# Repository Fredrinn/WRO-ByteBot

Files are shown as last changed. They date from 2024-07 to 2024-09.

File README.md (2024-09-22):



# WRO-Future Engineers

## ByteBots
### Robotic Solution - ByteBot  

We are Team ByteBots, consisting of Anthony Vargas, Miguelangel Moreno, and Yonathan González. We have developed an autonomous vehicle model to compete in the 2024 season of WRO Future Engineers. This repository houses a wide range of engineering resources related to our autonomous vehicle, designed to tackle challenging speed and skill tests.

## 📝 Contents

* **📸👥 Team Photo**  
  In this section, we present an official photo of our talented ByteBot team. This image captures the spirit of collaboration and dedication that has led us to develop a high-performance autonomous vehicle for the WRO Future Engineers competition. Meet the faces behind the project and discover the collective effort we've invested to achieve our goals.

* **📊📈 Diagram**  
  Here, we present a comprehensive diagram showing the internal workings and structure of our autonomous robot. This diagram provides a clear understanding of how we designed and assembled each essential part of our vehicle, including the sensor system, control unit, actuators, and the overall layout of the components.

* **🛠️🔧 Prototype Images**  
  In this section, you'll find various .pdf files with detailed photos of our robot. You can explore its innovative design, components, and key features up close. These images will allow you to appreciate the quality and precision with which we've built our autonomous vehicle for the WRO Future Engineers competition.

* **💻👩‍💻 Programming**  
  Here you will find the C++ code we developed for the operation of our autonomous robot. This programming file provides detailed information about the navigation algorithms, obstacle detection, and decision-making capabilities of our vehicle. We will be updating the code versions as we progress in the development and optimization of the robot.

* **🤖🎥 Robot Video**  
  In this section, we provide a link to a video located in the vehicle photo folder where you can see our robot in action.

## 📚 Introduction

To optimize the design, the solution was modeled in virtual simulations and used a minimal number of components, allowing for space savings. Significant effort was devoted to optimizing the robot's size and reducing material consumption.

The components used in our prototype are as follows:

- **Microcontroller**: Arduino UNO R3
- **Sensor**: HuskyLens
- **Motors**: DC Motor 6V
- **Servomotor**: Servomotor
- **Other components**: 18650 Batteries, LN298 Module, Jumpers, LEDs

### ⚙️💡 Operation

The journey of the robotic prototype begins with the use of HuskyLens, which provides precise data on the distance between the robot and surrounding objects. Once this data is obtained, the robot enters a second phase of conditional processing that allows it to determine its precise location on the game track.

The prototype can take two distinct approaches to act accordingly. On one hand, it can choose to follow a predefined or pre-programmed route, using sensor data to adjust its trajectory and avoid obstacles. This strategy is based on prior planning and precise execution to achieve the desired goal.

On the other hand, the prototype can also employ a more dynamic and adaptive approach. Using sensor information, the robot can continuously evaluate its surroundings and make real-time decisions to avoid obstacles and reach its goal in the most efficient way possible. This involves a greater capacity for reaction and adaptation to changing game conditions.

####  🚀✨ First Option

The robotic prototype extensively validates HuskyLens data to determine its exact position on the game track. It uses this information to follow a predefined and optimized path that ensures a smooth, fast, and precise journey. The robot maintains a constant and safe pace using the distance data recorded by HuskyLens, avoiding unnecessary stops to check for obstacles in its path.

#### 🧭✨ Second Option

When the ByteBot system detects obstacles through HuskyLens, a conditional logic is activated in Program 2. This program encodes variables and actions for the prototype to make dynamic decisions and adjust its trajectory to avoid obstacles. If an obstacle is detected, the prototype efficiently turns left or right.

The prototype uses HuskyLens data to identify the location and nature of obstacles, determining the optimal direction to avoid them and encoding the necessary instructions for the corresponding turn. This real-time response and adaptation capability is crucial for the prototype's success.

###  🤖⚙️ Action-Reaction

Our action-reaction principle is based on the idea that all vehicle components must work in perfect harmony to achieve optimal performance. The components and actions necessary to generate a reaction based on the received data are as follows:

1. **Sensor Activation**: Upon powering on the vehicle, the first action is to activate HuskyLens, which will provide distance data to locate the prototype at a specific point on the track. These sensors are crucial for obstacle detection and correct vehicle positioning.

2. **Obstacle Detection**: Once the prototype's location is known, the next action is to determine if obstacles are present. To achieve this, we have proposed implementing artificial intelligence (AI) capable of detecting these obstacles. Our team has decided to develop this AI using accessible and user-friendly tools like Teachable Machine. This way, we can leverage machine learning capabilities to train the system in obstacle detection.

3. **Reactions**: Once the prototype knows its location and the presence of obstacles on the track, two possible reactions are triggered:

   3.1. **Predefined Route**: The first reaction is to act as if the prototype is in Round 1, i.e., an obstacle-free track. To achieve this, we use known data such as the initial position, robot speed, track size, robot size, and turning angles. By using mathematical and physical principles, we can calculate a predefined route based on this data, thus avoiding the need to constantly read and analyze known data, saving time and improving efficiency.

   3.2. **Obstacle Detection and Response**: If the prototype detects an obstacle, indicating Round 2, a second reaction occurs. Since Round 2 presents obstacles, it is necessary to reduce the motor speed to avoid errors due to excessive speed.

      3.2.1. **Obstacle Monitoring**: The next action is to monitor the color of the obstacles. This way, we can predefine the vehicle's reaction, which consists of reducing the speed of the DC motors and turning the servomotor in the appropriate direction to provide optimal direction to the robot. This approach allows us to navigate safely and efficiently around obstacles.

<div align="center">

### Made with ❤️ by Bytebots Team

</div>

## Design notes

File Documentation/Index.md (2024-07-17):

# Index

## Documentation
- [Introduction](https://github.com/Fredrinn/WRO-ByteBot/blob/main/Documentation/Introduction.md)
- [README](https://github.com/Fredrinn/WRO-ByteBot/blob/main/README.md)

## Code
- [Bytebot - Code v1.0.1.cpp](https://github.com/Fredrinn/WRO-ByteBot/blob/main/Documentation/Code/Bytebot%20-%20Code%20v1.0.1.cpp)
- [Bytebot - Code v2.0.0.cpp](https://github.com/Fredrinn/WRO-ByteBot/blob/main/Documentation/Code/Bytebot%20-%20Code%20v2.0.0.cpp)
- [code.md](https://github.com/Fredrinn/WRO-ByteBot/blob/main/Documentation/Code/code.md)

## Diagrams
### Component Diagrams
- [Arduino electrical diagram + Motor Driver Shield.png](https://github.com/Fredrinn/WRO-ByteBot/blob/main/Documentation/Diagram/Diagrams/Arduino%20electrical%20diagram%20%2B%20Motor%20Driver%20Shield.png)
- [Arduino physical diagram + Motor Driver Shield.png](https://github.com/Fredrinn/WRO-ByteBot/blob/main/Documentation/Diagram/Diagrams/Arduino%20physical%20diagram%20%2B%20Motor%20Driver%20Shield.png)
- [ByteBots physical diagram.png](https://github.com/Fredrinn/WRO-ByteBot/blob/main/Documentation/Diagram/Diagrams/ByteBots%20physical%20diagram.png)
- [Bytebots electrical diagram.png](https://github.com/Fredrinn/WRO-ByteBot/blob/main/Documentation/Diagram/Diagrams/Bytebots%20electrical%20diagram.png)
- [Diagrams PDF.pdf](https://github.com/Fredrinn/WRO-ByteBot/blob/main/Documentation/Diagram/Diagrams/Diagrams%20PDF.pdf)
- [Esquema ByteBots - Motor Driver Shield + Arduino Mega.fzz](https://github.com/Fredrinn/WRO-ByteBot/blob/main/Documentation/Diagram/Diagrams/Esquema%20ByteBots%20-%20Motor%20Driver%20Shield%20%2B%20Arduino%20Mega.fzz)
- [Esquema_Bytebots.fzz](https://github.com/Fredrinn/WRO-ByteBot/blob/main/Documentation/Diagram/Diagrams/Esquema_Bytebots.fzz)

## Photos
### Team Photos
- [Team Photo.ARW](https://github.com/Fredrinn/WRO-ByteBot/blob/main/Documentation/Photos/Team%C2%B4s%20Photos/Team%20Photo.ARW)

### Robot Photos
- [Lado derecho.jpg](https://github.com/Fredrinn/WRO-ByteBot/blob/main/Documentation/Photos/Vehicle's%20photos/Lado%20derecho.jpg)
- [Lado frontal.jpg](https://github.com/Fredrinn/WRO-ByteBot/blob/main/Documentation/Photos/Vehicle's%20photos/Lado%20frontal.jpg)
- [Lado izquierdo.jpg](https://github.com/Fredrinn/WRO-ByteBot/blob/main/Documentation/Photos/Vehicle's%20photos/Lado%20izquierdo.jpg)
- [Lado trasero.jpg](https://github.com/Fredrinn/WRO-ByteBot/blob/main/Documentation/Photos/Vehicle's%20photos/Lado%20trasero.jpg)
- [Parte de abajo.jpg](https://github.com/Fredrinn/WRO-ByteBot/blob/main/Documentation/Photos/Vehicle's%20photos/Parte%20de%20abajo.jpg)
- [Parte de arriba.jpg](https://github.com/Fredrinn/WRO-ByteBot/blob/main/Documentation/Photos/Vehicle's%20photos/Parte%20de%20arriba.jpg)

### Vehicle Video
- [Vehile-video.md](https://github.com/Fredrinn/WRO-ByteBot/blob/main/Documentation/Photos/Vehicle's%20photos/Vehile-video.md)

## Robot Assembly
- [Assemble Model A.pdf](https://github.com/Fredrinn/WRO-ByteBot/blob/main/Documentation/Robot-assembly/Assemble%20Model%20A.pdf)
- [Assemble Model B.pdf](https://github.com/Fredrinn/WRO-ByteBot/blob/main/Documentation/Robot-assembly/Assemble%20Model%20B.pdf)
- [Model A.png](https://github.com/Fredrinn/WRO-ByteBot/blob/main/Documentation/Robot-assembly/Model%20A.png)
- [Model B.jpg](https://github.com/Fredrinn/WRO-ByteBot/blob/main/Documentation/Robot-assembly/Model%20B.jpg)
- [assembly.md](https://github.com/Fredrinn/WRO-ByteBot/blob/main/Documentation/Robot-assembly/assembly.md)

## Additional Resources
- [01. Diagram Description.md](https://github.com/Fredrinn/WRO-ByteBot/blob/main/Documentation/Diagram/01.%20Diagram%20Description.md)
- [02. Energy management.md](https://github.com/Fredrinn/WRO-ByteBot/blob/main/Documentation/Diagram/02.%20Energy%20management.md)
- [03. Sensor management.md](https://github.com/Fredrinn/WRO-ByteBot/blob/main/Documentation/Diagram/03.%20Sensor%20management.md)
- [04. BOM.md](https://github.com/Fredrinn/WRO-ByteBot/blob/main/Documentation/Diagram/04.%20BOM.md)
- [05. Mobility Management - Motors.md](https://github.com/Fredrinn/WRO-ByteBot/blob/main/Documentation/Diagram/05.%20Mobility%20Management%20-%20Motors.md)

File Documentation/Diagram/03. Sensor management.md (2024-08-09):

# Descripción Técnica y Razones de Selección de Sensores en el Proyecto de Robot

Este proyecto utiliza varios sensores que cumplen funciones clave para la operación del robot. A continuación se proporciona una descripción técnica detallada de cada sensor, junto con las razones por las cuales fueron seleccionados.

## Sensor Ultrasónico HC-SR04
**Función:** Detección de distancia de objetos y ubicación del dispositivo.

**Descripción Técnica:**
- **Rango de detección:** 2 cm a 400 cm, con una precisión de ±3 mm.
- **Frecuencia de operación:** 40 kHz.
- **Voltaje de operación:** 5V DC.

**Por qué es bueno:** Este sensor es ideal para detectar objetos a diferentes distancias con alta precisión, lo que lo convierte en una opción confiable para la navegación autónoma. 

**¿Por qué lo elegimos?** Elegimos el HC-SR04 por su probada efectividad en medir distancias con gran precisión y fiabilidad. Su capacidad para funcionar en un amplio rango de distancias lo hace perfecto para nuestro robot, que necesita detectar obstáculos tanto cercanos como lejanos. Además, su compatibilidad con Arduino y su simplicidad de uso lo hacen muy accesible para el equipo, permitiéndonos concentrarnos en otros aspectos del diseño sin preocuparnos por la complejidad de su implementación.

## Módulo Cámara HuskyLens
**Función:** Visión artificial.

**Descripción Técnica:**
- **Resolución de imagen:** 320x240 píxeles.
- **Interfaces de comunicación:** I2C, UART.
- **Funciones integradas:** Reconocimiento de rostros, seguimiento de objetos, detección de líneas y códigos QR.

**Por qué es buena:** La cámara HuskyLens no solo captura imágenes, sino que también tiene capacidades integradas de procesamiento de visión artificial, lo que reduce la carga de trabajo del microcontrolador. Esto permite que el robot interprete su entorno visualmente y tome decisiones basadas en la información capturada, mejorando significativamente su rendimiento en tareas complejas.

**¿Por qué lo elegimos?** Elegimos la HuskyLens por su avanzada tecnología de visión artificial, que permite a nuestro robot realizar tareas de reconocimiento y seguimiento sin necesidad de procesadores adicionales. Su capacidad para manejar múltiples funciones visuales en tiempo real es crucial para el desarrollo de un robot autónomo sofisticado. Además, su facilidad de uso a través de interfaces como I2C y UART nos brinda flexibilidad en la integración con otros componentes del sistema.

## Módulo Sensor IR (Infrarrojo)
**Función:** Detección de obstáculos cercanos y cobertura de puntos muertos.

**Descripción Técnica:**
- **Rango de detección:** 2 cm a 30 cm.
- **Ángulo de detección:** 35 grados.
- **Voltaje de operación:** 3.3V a 5V DC.

**Por qué es bueno:** Este sensor es perfecto para detectar objetos cercanos que podrían pasar desapercibidos por otros sensores de mayor alcance, como el ultrasónico. Es pequeño, eficiente en consumo de energía, y proporciona una rápida respuesta en la detección de obstáculos, lo que es crucial para evitar colisiones en entornos complejos.

**¿Por qué lo elegimos?** El sensor IR fue seleccionado por su capacidad para detectar obstáculos en áreas que otros sensores, como el ultrasónico, podrían no cubrir debido a su mayor rango de operación. Su tamaño compacto y bajo consumo de energía son ideales para integrar en nuestro robot sin afectar su diseño o autonomía. Además, la rápida respuesta que ofrece es esencial para garantizar la seguridad y eficiencia del robot en situaciones donde se requiere una detección inmediata de obstáculos.

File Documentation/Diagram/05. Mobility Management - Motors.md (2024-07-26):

### 📊 Calculation of Robot Torque 🤖

To calculate the robot torque, we follow these steps:

1. **Determining the force exerted by the robot due to its weight.** ⚖️
2. **Calculating the wheel radius.** 🔄
3. **Calculating torque using force and wheel radius.** 🔧

#### 1. Determination of Force

The total weight of the robot, including the batteries, is \( 0.98 \) kg. The force \( F \) exerted by the robot due to its weight is calculated as:

Arduino  $` F = m \times g `$

Where:
- \( m \) is the mass of the robot (\( 0.98 \) kg)
- \( g \) is the acceleration due to gravity (\( 9.81 \) m/s²)

Arduino  $` F = 0.98 \, \text{kg} \times 9.81 \, \text{m/s}^2 = 9.614 \, \text{N} `$

The force exerted by the robot due to its weight is approximately \( 9.614 \) N.

#### 2. Calculation of Wheel Radius

The diameter of the wheels is \( 64 \) mm. The radius \( r \) is half of the diameter:

Arduino  $` r = \frac{d}{2} = \frac{64 \, \text{mm}}{2} = 32 \, \text{mm} = 0.032 \, \text{m} `$

#### 3. Calculation of Torque

The torque \( \tau \) is calculated using the formula:

Arduino  $` \tau = F \times r `$

Substituting the values of force and radius into the formula:

Arduino  $` \tau = 9.614 \, \text{N} \times 0.032 \, \text{m} = 0.3076 \, \text{Nm} `$

Therefore, the torque exerted by the robot is approximately \( 0.3076 \) Nm.

### ⚙️ Conclusion and Motor Recommendation

The motor should provide at least \( 0.3076 \) Nm of torque. It is recommended to use a \( 12 \) V DC motor with the following specifications:

- **Nominal Torque**: \( 4-5 \) kg-cm (approximately \( 0.4-0.5 \) Nm), to provide a safety margin.
- **Current Capacity**: \( 2-3 \) A, to ensure the motor can handle the required current under load.

#### Example of Suggested Motor

- **12V DC Motor 300RPM with High Torque**: These motors typically have a torque of around \( 4-5 \) kg-cm and can handle higher currents, ensuring the motor can efficiently move the robot.

### 🔍 Final Discussion

Selecting this motor is the best option due to its ability to provide torque greater than required, ensuring smooth and efficient operation of the robot. Additionally, its capability to handle higher currents allows robust operation under various load conditions. This provides a safety margin crucial for avoiding overloads and ensuring motor longevity. Therefore, the \( 12 \) V DC motor with the mentioned specifications is ideal for this project. 🚀

---

### 📊 Cálculo del Torque del Robot 🤖

Para calcular el torque del robot, seguimos estos pasos:

1. **Determinación de la fuerza ejercida por el robot debido a su peso.** ⚖️
2. **Cálculo del radio de las ruedas.** 🔄
3. **Cálculo del torque utilizando la fuerza y el radio de las ruedas.** 🔧

#### 1. Determinación de la Fuerza

El peso total del robot, incluyendo las baterías, es de \( 0.98 \) kg. La fuerza \( F \) ejercida por el robot debido a su peso se calcula como:

Arduino  $` F = m \times g `$

Donde:
- \( m \) es la masa del robot (\( 0.98 \) kg)
- \( g \) es la aceleración debido a la gravedad (\( 9.81 \) m/s²)

Arduino  $` F = 0.98 \, \text{kg} \times 9.81 \, \text{m/s}^2 = 9.614 \, \text{N} `$

La fuerza ejercida por el robot debido a su peso es aproximadamente \( 9.614 \) N.

#### 2. Cálculo del Radio de las Ruedas

El diámetro de las ruedas es \( 64 \) mm. El radio \( r \) es la mitad del diámetro:

Arduino  $` r = \frac{d}{2} = \frac{64 \, \text{mm}}{2} = 32 \, \text{mm} = 0.032 \, \text{m} `$

#### 3. Cálculo del Torque

El torque \( \tau \) se calcula utilizando la fórmula:

Arduino  $` \tau = F \times r `$

Sustituyendo los valores de la fuerza y el radio en la fórmula:

Arduino  $` \tau = 9.614 \, \text{N} \times 0.032 \, \text{m} = 0.3076 \, \text{Nm} `$

Por lo tanto, el torque ejercido por el robot es aproximadamente \( 0.3076 \) Nm.

### ⚙️ Conclusión y Recomendación del Motor

El motor debe proporcionar al menos \( 0.3076 \) Nm de torque. Se recomienda utilizar un motor DC de \( 12 \) V con las siguientes especificaciones:

- **Torque Nominal**: \( 4-5 \) kg-cm (aproximadamente \( 0.4-0.5 \) Nm), para proporcionar un margen de seguridad.
- **Capacidad de Corriente**: \( 2-3 \) A, para asegurar que el motor pueda manejar la corriente requerida bajo carga.

#### Ejemplo de Motor Sugerido

- **Motor DC 12V 300RPM con Alto Torque**: Estos motores suelen tener un torque de alrededor de \( 4-5 \) kg-cm y son capaces de manejar corrientes más altas, asegurando que el motor pueda mover el robot de manera eficiente.

### 🔍 Discusión Final

Seleccionar este motor es la mejor opción debido a su capacidad para proporcionar un torque mayor al requerido, asegurando un funcionamiento suave y eficiente del robot. Además, su capacidad para manejar corrientes más altas permite una operación robusta bajo diversas condiciones de carga. Esto proporciona un margen de seguridad crucial para evitar sobrecargas y asegurar la longevidad del motor. Por lo tanto, el motor DC de \( 12 \) V con las especificaciones mencionadas es ideal para este proyecto. 🚀

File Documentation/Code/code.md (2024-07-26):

# Documentación del Proyecto Bytebots

## C++ Tecnologías Utilizadas

Este proyecto está desarrollado utilizando las siguientes tecnologías y plataformas:

<span>
    Arduino
    C++
</span>

Descripción de la imagen

## C++ Descripción

Este proyecto utiliza un motor servo y un sensor de visión AI HuskyLens para detectar colores y mover el servo según los IDs de color detectados. El proyecto involucra los siguientes componentes:

- **Motor Servo**: Controlado mediante la biblioteca `Servo.h` para moverse a posiciones específicas.
- **HuskyLens**: Un sensor de visión AI que utiliza la biblioteca `HUSKYLENS.h` para la detección y reconocimiento de colores.
- **SoftwareSerial**: Utilizado para comunicar con el HuskyLens mediante comunicación serial.

## C++ Funcionalidad

El sistema opera de la siguiente manera:

1. **Inicialización**: 
   - El motor servo se conecta a un pin especificado.
   - Se inicializa la comunicación serial tanto para el serial estándar como para el serial por software (para HuskyLens).
   - Se inicializa el HuskyLens y se configura para usar el algoritmo de reconocimiento de colores.

2. **Detección de Colores y Control del Servo**:
   - En el bucle principal, el sistema solicita datos del HuskyLens.
   - Si el HuskyLens detecta un color aprendido, lee el resultado.
   - Si el ID de color detectado es `1`, el servo se mueve a la posición izquierda.
   - El sistema luego espera a que se detecte el ID de color `2` para mover el servo a la posición centrada.

3. **Movimiento del Servo y Verificación del Centro**:
   - La función `moverServo` se usa para mover el servo a una posición especificada y verificar si está centrado.
   - La función `verificarCentro` verifica si el servo está dentro del rango de posición centrada e imprime el estado en el monitor serial.

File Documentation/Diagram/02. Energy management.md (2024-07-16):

# ByteBot Battery Configuration

## Overview

This document provides detailed technical information on the battery configuration used in ByteBot. The setup involves six 18650 batteries arranged in a 3S2P configuration, optimizing both voltage and capacity.

## Configuration Details

### Battery Configuration: 3S2P

- **3S (Series)**: Three batteries connected in series to add their voltages.
- **2P (Parallel)**: Two of these series connected in parallel to add their capacities.

### Electrical Specifications

- **Total Voltage (Nominal)**: `11.1V`
- **Total Voltage (Fully Charged)**: `12.6V`
- **Total Capacity (Amperage)**: `4000mAh (4Ah)`

### Charging Information

- **Charge Rate**: Typically 0.5C to 1C
- **Charging Time at 0.5C**: `2 to 3 hours`
- **Charging Time at 1C**: `1.5 to 2 hours`

### Maximum Voltage

- **Maximum Voltage**: `12.6V`

## Technical Summary

This six-cell 18650 battery configuration in a 3S2P arrangement provides a robust solution for applications requiring a balance between high voltage and extended capacity. The nominal voltage of 11.1V ensures stable operation, while the fully charged voltage of 12.6V offers a performance boost when needed. With a total capacity of 4000mAh, ByteBot is equipped for extended periods of operation without frequent recharges.

### ⚡ Voltage Details

- **Nominal Voltage**: `11.1V`
- **Fully Charged Voltage**: `12.6V`

### 🔋 Capacity Details

- **Total Capacity**: `4000mAh (4Ah)`

### ⏳ Charging Time

- **At 0.5C**: `2 to 3 hours`
- **At 1C**: `1.5 to 2 hours`

## Optimization and Safety Reasons

This 3S2P configuration with 18650 batteries is optimal due to its ideal balance between high voltage and high capacity, essential for applications requiring prolonged operation and robust performance, such as ByteBot. By combining batteries in series and parallel, a nominal voltage of 11.1V and a total capacity of 4000mAh is achieved, providing sufficient power without frequent recharges. The approximate weight of this configuration is 270 grams, considering that each 18650 battery weighs around 45 grams.

### Safety Recommendations for 18650 Battery Configuration

1. **Handling and Storage**:
   - Avoid short circuits: Never allow the battery terminals to come into contact with metallic objects.
   - Store in a dry place at room temperature, away from flammable materials.

2. **Mounting**:
   - Use an appropriate holder to keep the batteries firmly in place.
   - Ensure that the series and parallel connections are properly insulated to prevent short circuits.

3. **Charging**:
   - Use a balanced charger specifically for lithium-ion batteries, with overcharge protection.
   - Do not leave batteries charging unattended.

4. **Usage**:
   - Avoid complete battery discharge; keep the voltage above 3V per cell to prolong battery life.
   - Monitor battery temperature during use; if they become too hot, stop operation and let them cool down.

5. **Emergency Handling**:
   - Have a Class D fire extinguisher, suitable for metal fires, on hand in case a battery overheats or catches fire.
   - In case of leakage, avoid contact with skin and eyes; wash with plenty of water and seek medical attention.

This configuration not only maximizes ByteBot's operational efficiency but also meets the necessary safety and reliability standards in advanced robotic engineering, ensuring safe and prolonged performance.

## Additional Resources

For more information on battery configuration, you can check the following resources:

- **Video**: [Battery Configuration](https://youtu.be/Cti496Aw1ew?si=FzMWoOU4gcUDVYFR)
  Battery Configuration (https://youtu.be/Cti496Aw1ew?si=FzMWoOU4gcUDVYFR)

- **Website**: [Building a Lithium-Ion Battery Pack](https://www.facilelectro.es/montar-un-pack-de-baterias-de-litio/)

---

## Energy Consumption by Component

**Arduino Mega 2560:**
- Typical consumption: Approximately 50 mA in active mode. 🤖
- Power supply: 7V to 12V, provided by the 18650 batteries through the Motor Driver Shield. 🔋

**L298N Motor Driver Module:**
- Consumption depends on the motor load. 🛠️
- Power supply: Provided by the 18650 batteries. 🔌

**HC-SR04 Ultrasonic Sensor:**
- Low consumption, typically around 15 mA during measurement. 📏
- Power supply: Provided by the 5V pins on the Arduino. 🔌

**IR Sensor Module:**
- Variable consumption, generally in the range of 20-30 mA depending on the active or inactive state. 🕵️‍♂️
- Power supply: Provided by the 5V pins on the Arduino. 🔌

**Huskylens Camera Module:**
- Power supply: Voltage from 3.3V to 5.0V

## Result of the Debate on Energy Optimization

After extensive debate among team members, it was concluded that our first prototype version had a total of 2 18650 batteries and a weight of 800g, which is below the allowed limit of 1.5kg. This means that adding more batteries would not pose a significant problem. Considering each 18650 battery weighs approximately 45g, adding 4 additional batteries would increase the weight by 180g, bringing the total weight to 980g, still within the permitted limit.

The new battery configuration was designed in a 3S2P arrangement (3 in series and 2 in parallel). In this arrangement, three sets of two batteries in parallel are connected in series to provide a total voltage of 11.1V and an increased capacity of 4000mAh.

This decision was made because with the 7.4V resulting from using only 2 batteries, we could barely utilize 61.6% of a 12V DC motor's capacity. By increasing the number of batteries, the voltage is raised to 11.1V, which allows us to utilize 92.5% of the 12V motor's capacity. This significantly improves the balance between the robot's speed and torque, optimizing its performance in competitions.

In the 3S2P arrangement, each pair of batteries connected in parallel maintains the same nominal voltage of 3.7V but doubles the capacity. Then, by connecting three of these pairs in series, the voltage is tripled to 11.1V while maintaining a total capacity of 4000mAh. This configuration provides an optimal balance between capacity and voltage, ensuring adequate and stable power for all robot components.

---

# Configuración de Baterías de ByteBot

## Descripción General

Este documento proporciona información técnica detallada sobre la configuración de baterías utilizada en ByteBot. La configuración involucra seis baterías 18650 dispuestas en una configuración 3S2P, optimizando tanto el voltaje como la capacidad.

## Detalles de la Configuración

### Configuración de Baterías: 3S2P

- **3S (Serie)**: Tres baterías conectadas en serie para sumar sus voltajes.
- **2P (Paralelo)**: Dos de estas series conectadas en paralelo para sumar sus capacidades.

### Especificaciones Eléctricas

- **Voltaje Total (Nominal)**: `11.1V`
- **Voltaje Total (Completamente Cargadas)**: `12.6V`
- **Capacidad Total (Amperaje)**: `4000mAh (4Ah)`

### Información de Carga

- **Tasa de Carga**: Típicamente 0.5C a 1C
- **Tiempo de Carga a 0.5C**: `2 a 3 horas`
- **Tiempo de Carga a 1C**: `1.5 a 2 horas`

### Voltaje Máximo

- **Voltaje Máximo**: `12.6V`

## Resumen Técnico

Esta configuración de batería de seis celdas 18650 en una disposición 3S2P proporciona una solución robusta para aplicaciones que requieren un equilibrio entre alto voltaje y capacidad extendida. El voltaje nominal de 11.1V asegura una operación estable, mientras que el voltaje completamente cargado de 12.6V ofrece un impulso de rendimiento cuando es necesario. Con una capacidad total de 4000mAh, ByteBot está equipado para períodos extendidos de operación sin recargas frecuentes.

### ⚡ Detalles del Voltaje

- **Voltaje Nominal**: `11.1V`
- **Voltaje Completamente Cargado**: `12.6V`

### 🔋 Detalles de Capacidad

- **Capacidad Total**: `4000mAh (4Ah)`

### ⏳ Tiempo de Carga

- **A 0.5C**: `2 a 3 horas`
- **A 1C**: `1.5 a 2 horas`

## Razones de Optimización y Seguridad

Esta configuración de 3S2P con baterías 18650 es óptima debido a su equilibrio ideal entre alto voltaje y alta capacidad, esencial para aplicaciones que requieren una operación prolongada y un rendimiento robusto, como en el caso de ByteBot. Al combinar baterías en serie y paralelo, se logra un voltaje nominal de 11.1V y una capacidad total de 4000mAh, proporcionando suficiente potencia sin necesidad de recargas frecuentes. El peso aproximado de esta configuración es de 270 gramos, considerando que cada batería 18650 pesa alrededor de 45 gramos.

### Recomendaciones de Seguridad para la Configuración de Baterías 18650

1. **Manipulación y Almacenamiento**:
   - Evitar cortocircuitos: Nunca permita que los terminales de las baterías entren en contacto con objetos metálicos.
   - Almacenar en un lugar seco y a temperatura ambiente, lejos de materiales inflamables.

2. **Montaje**:
   - Usar un soporte adecuado para mantener las baterías firmemente en su lugar.
   - Asegurarse de que las conexiones de serie y paralelo estén correctamente aisladas para prevenir cortocircuitos.

3. **Carga**:
   - Utilizar un cargador balanceado específico para baterías de litio-ion, que tenga protección contra sobrecarga.
   - No dejar las baterías cargándose sin supervisión.

4. **Uso**:
   - Evitar la descarga completa de las baterías; mantener el voltaje por encima de 3V por celda para prolongar su vida útil.
   - Monitorear la temperatura de las baterías durante el uso; si se calientan demasiado, detener la operación y dejar que se enfríen.

5. **Manejo de Emergencias**:
   - Tener un extintor de clase D a mano, adecuado para incendios de metales, en caso de que una batería se sobrecaliente o se incendie.
   - En caso de fuga, evitar el contacto con la piel y los ojos; lavar con abundante agua y buscar atención médica.

Esta configuración no solo maximiza la eficiencia operativa de ByteBot, sino que también cumple con los estándares de seguridad y fiabilidad necesarios en la ingeniería robótica avanzada, garantizando un rendimiento seguro y prolongado.

## Recursos Adicionales

Para obtener más información sobre la configuración de baterías, puedes consultar los siguientes recursos:

- **Video**: [Configuración de Baterías](https://youtu.be/Cti496Aw1ew?si=FzMWoOU4gcUDVYFR)
  Configuración de Baterías (https://youtu.be/Cti496Aw1ew?si=FzMWoOU4gcUDVYFR)

- **Sitio Web**: [Montar un Pack de Baterías de Litio](https://www.facilelectro.es/montar-un-pack-de-baterias-de-litio/)
  
---

## Consumo de Energía por Componente

**Arduino Mega 2560:**
- Consumo típico: Aproximadamente 50 mA en modo activo. 🤖
- Alimentación: 7V a 12V, que provendrá de las baterías 18650 a través del Motor Driver Shield. 🔋

**L298N Motor Driver Module:**
- Consumo depende de la carga del motor. 🛠️
- Alimentación: Proveniente de las baterías 18650. 🔌

**HC-SR04 Ultrasonic Sensor:**
- Consumo bajo, típicamente alrededor de 15 mA durante la medición. 📏
- Alimentación: Proveniente de los pines de 5V del Arduino. 🔌

**IR Sensor Module:**
- Consumo variable, generalmente en el rango de 20-30 mA dependiendo del estado activo o inactivo. 🕵️‍♂️
- Alimentación: Proveniente de los pines de 5V del Arduino. 🔌

**Huskylens Camera Module:**
- Alimentación: Tensión de 3.3V a 5.0V
  
## Resultado del Debate sobre la Optimización de Energía

Después de un extenso debate entre los miembros del equipo, se concluyó que nuestra primera versión del prototipo contaba con un total de 2 baterías 18650 y un peso de 800g, algo por debajo del límite permitido de 1.5kg. Esto significa que añadir más baterías no representaría un gran problema. Considerando que cada batería 18650 pesa aproximadamente 45g, añadir 4 baterías adicionales incrementaría el peso en 180g, llevando el peso total a 980g, aún dentro del límite permitido.

La nueva configuración de las baterías se diseñó en un arreglo 3s2p (3 en serie y 2 en paralelo). En este arreglo, tres conjuntos de dos baterías en paralelo se conectan en serie para proporcionar un voltaje total de 11.1V y una capacidad aumentada de 4000mAh.

Esta decisión se tomó debido a que con los 7.4V resultantes de utilizar solo 2 baterías, apenas podríamos aprovechar el 61.6% de la capacidad de un motor DC de 12V. Al aumentar la cantidad de baterías, se incrementa el voltaje a 11.1V, lo que permite aprovechar un 92.5% de la capacidad del motor de 12V. Esto mejora significativamente el equilibrio entre velocidad y torque del robot, optimizando su rendimiento en las competencias.

En el arreglo 3s2p, cada par de baterías conectadas en paralelo mantiene el mismo voltaje nominal de 3.7V, pero duplica la capacidad. Luego, al conectar tres de estos pares en serie, se triplica el voltaje a 11.1V mientras se mantiene la capacidad total de 4000mAh. Esta configuración proporciona un equilibrio óptimo entre la capacidad y el voltaje, asegurando una alimentación adecuada y estable para todos los componentes del robot.

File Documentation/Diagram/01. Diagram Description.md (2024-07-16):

# Technical Description of System Diagram

## Main Components

1. **Arduino Mega 2560 Board**:
   - Located at the center of the diagram.
   - Provides control and logic for the system.
   - Key connections:
     - Powered by batteries.
     - Sensors and actuators connected to various pins.

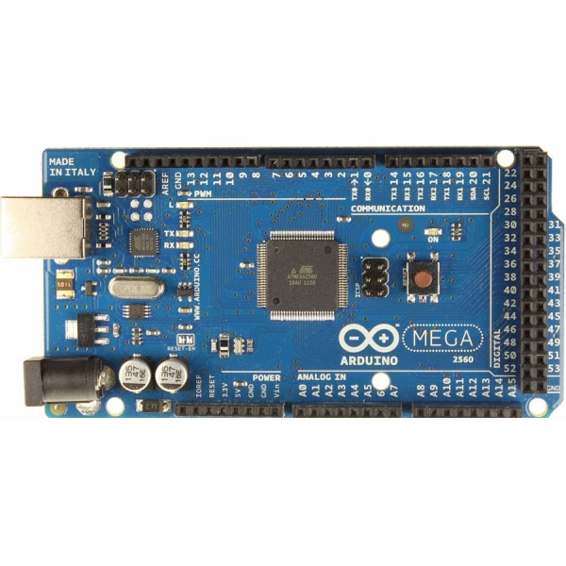
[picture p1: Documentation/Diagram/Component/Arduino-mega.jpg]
Arduino Mega
   <br>

2. **L298N Motor Driver Module**:
   - Positioned to the left of the Arduino board.
   - Controls the DC motor and servo.
   - Key connections:
     - Powered and controlled by Arduino.
     - Outputs to DC motor and servo.

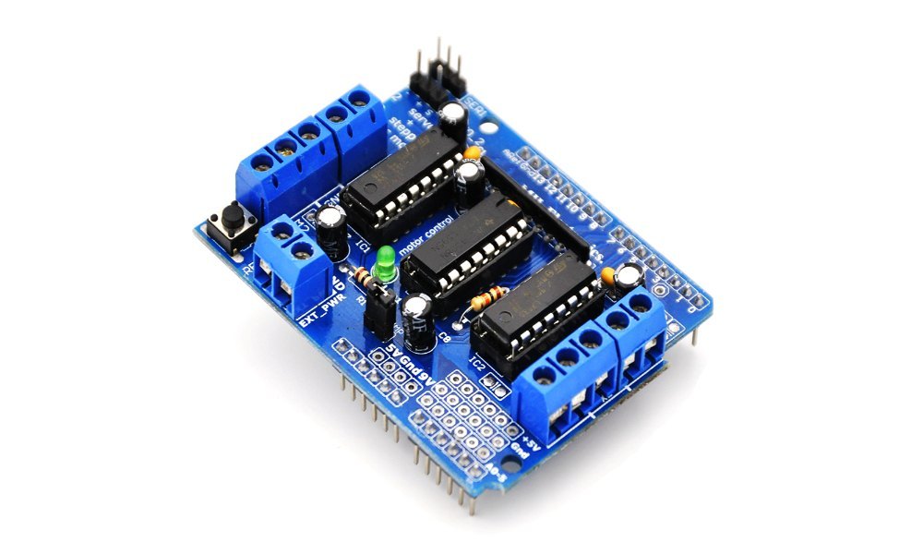
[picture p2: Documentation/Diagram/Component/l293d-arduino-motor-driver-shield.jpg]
L298N Motor Driver
   <br>

3. **18650 Batteries**:
   - Six batteries located on the left, connected in series to provide power.
   - Connection to motor driver and the Arduino board.

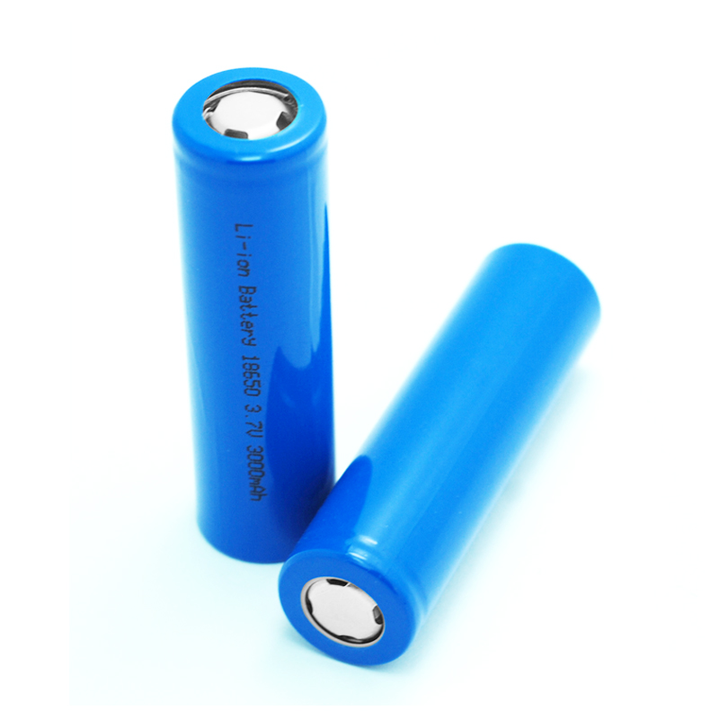
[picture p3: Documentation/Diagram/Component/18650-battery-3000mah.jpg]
18650 Batteries
   <br>

4. **HC-SR04 Ultrasonic Sensor**:
   - Located in the bottom right of the diagram.
   - Used for measuring distances to objects in front of the system.
   - Connections to Arduino digital pins for trigger and echo.

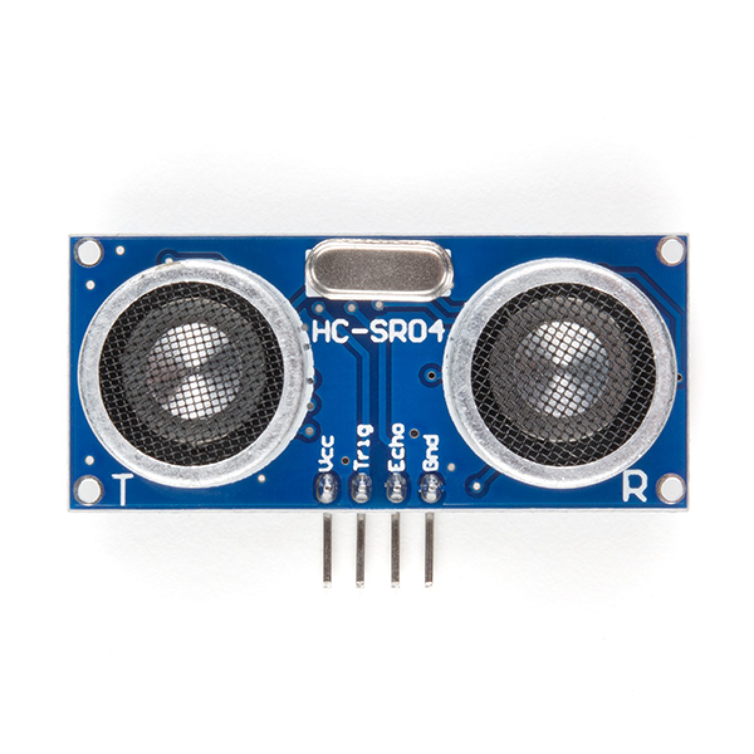
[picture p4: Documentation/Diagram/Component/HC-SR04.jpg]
HC-SR04 Ultrasonic Sensor
   <br>

5. **IR Sensor Module**:
   - Positioned just left of the ultrasonic sensor.
   - Used for detecting nearby obstacles.
   - Connections to Arduino digital pins.

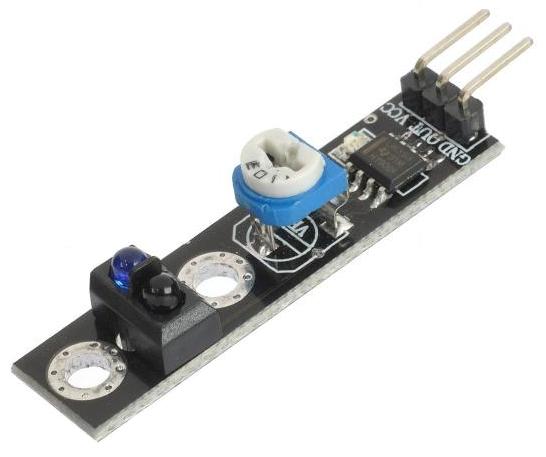
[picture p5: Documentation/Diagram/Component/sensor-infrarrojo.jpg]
IR Sensor
   <br>

6. **Camera Module**:
   - Located in the top right of the diagram.
   - Connected to the Arduino board for image capture.
   - Power and communication connected through specific pins.

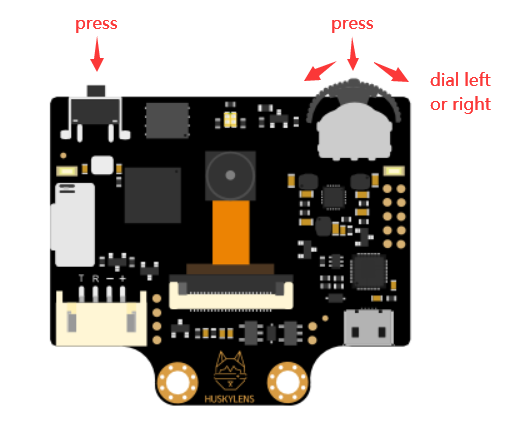
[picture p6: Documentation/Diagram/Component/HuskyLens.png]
Camera Module
   <br>

## Detailed Connections

- **Power**:
  - 18650 batteries are connected in series, providing power to both the L298N motor driver and the Arduino Mega board.
  - Red cables indicate positive voltage connections (+), and black cables indicate ground connections (-).

- **Motor Control**:
  - The L298N module receives control signals from the Arduino board to manage the DC motor and servo.
  - The DC motor is connected to the outputs of the L298N for speed and direction control.
  - The servo motor is also connected to the L298N for position control.

- **Sensors**:
  - The HC-SR04 ultrasonic sensor connects to Arduino digital pins for trigger and echo functionality.
  - The IR sensor module is connected to digital pins for obstacle detection.

- **Communication and Additional Sensors**:
  - The camera module is connected to the Arduino board via specific pins for communication and power.

## Operational Technical Description

The system is designed to function as an autonomous mobile robot. The Arduino Mega board acts as the brain of the system, controlling the movement of the DC motor and servo motor through the L298N module. The 18650 batteries provide the necessary power for the entire system.

The HC-SR04 ultrasonic sensor and IR module are used for obstacle detection, allowing the Arduino to receive data about object proximity and adjust motor direction accordingly to avoid collisions.

The camera module adds vision capabilities to the system, enabling the capture of images or videos that can be processed for navigation or object recognition.

---

# Descripción Técnica del Diagrama del Sistema

## Componentes Principales

1. **Placa Arduino Mega 2560**:
   - Ubicada en el centro del diagrama.
   - Proporciona el control y la lógica para el sistema.
   - Conexiones principales:
     - Alimentación desde baterías.
     - Sensores y actuadores conectados a varios pines.

   Arduino Mega<br>

2. **Módulo Driver de Motores L298N**:
   - Ubicado a la izquierda de la placa Arduino.
   - Controla el motor de corriente continua (DC motor) y el servo.
   - Conexiones principales:
     - Alimentación y control desde Arduino.
     - Salidas a motor DC y servo.

   L298N Motor Driver<br>

3. **Baterías 18650**:
   - Seis baterías ubicadas a la izquierda, conectadas en serie para proporcionar alimentación.
   - Conexión al driver de motores y a la placa Arduino.

   18650 Batteries<br>

4. **Sensor Ultrasónico HC-SR04**:
   - Ubicado en la parte inferior derecha del diagrama.
   - Utilizado para medir la distancia de objetos delante del sistema.
   - Conexiones a pines digitales en Arduino para trigger y echo.

   HC-SR04 Ultrasonic Sensor<br>

5. **Módulo Sensor IR (Infrarrojo)**:
   - Ubicado justo a la izquierda del sensor ultrasónico.
   - Utilizado para la detección de obstáculos cercanos.
   - Conexiones a pines digitales en Arduino.

   Sensor IR<br>

6. **Módulo Cámara**:
   - Ubicado en la parte superior derecha del diagrama.
   - Conectado a la placa Arduino para la captura de imágenes.
   - Alimentación y comunicación conectadas a través de pines específicos.

   Módulo Cámara<br>

## Conexiones Detalladas

- **Alimentación**:
  - Las baterías 18650 están conectadas en serie y alimentan tanto el driver de motores L298N como la placa Arduino Mega.
  - Los cables rojos indican conexiones de voltaje positivo (+) y los cables negros indican conexiones a tierra (-).

- **Control de Motores**:
  - El módulo L298N recibe señales de control desde la placa Arduino para manejar el motor DC y el servo.
  - El motor DC está conectado a las salidas del L298N, permitiendo su control de velocidad y dirección.
  - El servo motor también está conectado al L298N para control de posición.

- **Sensores**:
  - El sensor ultrasónico HC-SR04 tiene conexiones a los pines digitales del Arduino para los pines de trigger y echo.
  - El módulo sensor IR está conectado a pines digitales para detección de obstáculos.

- **Comunicación y Sensores Adicionales**:
  - El módulo cámara está conectado a la placa Arduino mediante pines específicos para comunicación y alimentación.

## Descripción Técnica del Funcionamiento

El sistema está diseñado para funcionar como un robot móvil autónomo. La placa Arduino Mega actúa como el cerebro del sistema, controlando el movimiento del motor DC y el servo motor a través del módulo L298N. Las baterías 18650 proporcionan la energía necesaria para todo el sistema.

El sensor ultrasónico HC-SR04 y el módulo IR se utilizan para la detección de obstáculos, permitiendo que el Arduino reciba datos sobre la proximidad de objetos y ajuste la dirección del motor en consecuencia para evitar colisiones.

La cámara añade capacidades de visión al sistema, permitiendo la captura de imágenes o videos que pueden ser procesados para navegación o reconocimiento de objetos.

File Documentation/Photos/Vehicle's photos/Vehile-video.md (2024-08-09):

### Enlace al Video

<a href="https://www.youtube.com/watch?v=M7r2FSRNm-M?si=92GTvmqhkAq8Kt1_" target="_blank">
    Ver video de funcionamiento del robot
</a>

#### Descripción en Español
Video que muestra el funcionamiento autónomo de nuestro robot utilizando sensores avanzados y algoritmos de inteligencia artificial para una navegación eficiente y segura.

#### Description in English
Video showcasing the autonomous operation of our robot using advanced sensors and AI algorithms for efficient and safe navigation.

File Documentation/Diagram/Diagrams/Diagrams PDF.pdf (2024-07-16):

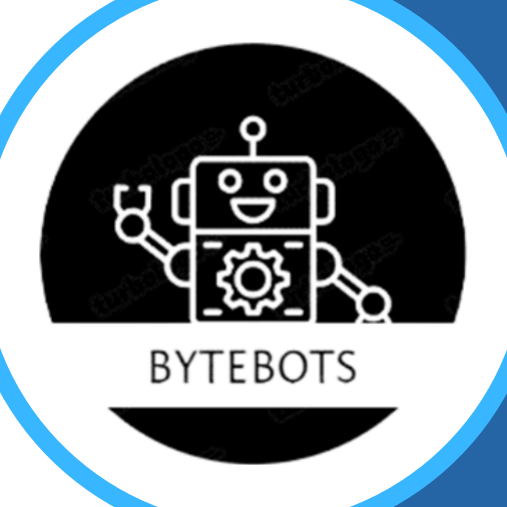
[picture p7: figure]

# DIAGRAMS

# TEAM BYTEBOTS

Let'

s learn together about this wiring diagram and
connection.

# INDEX

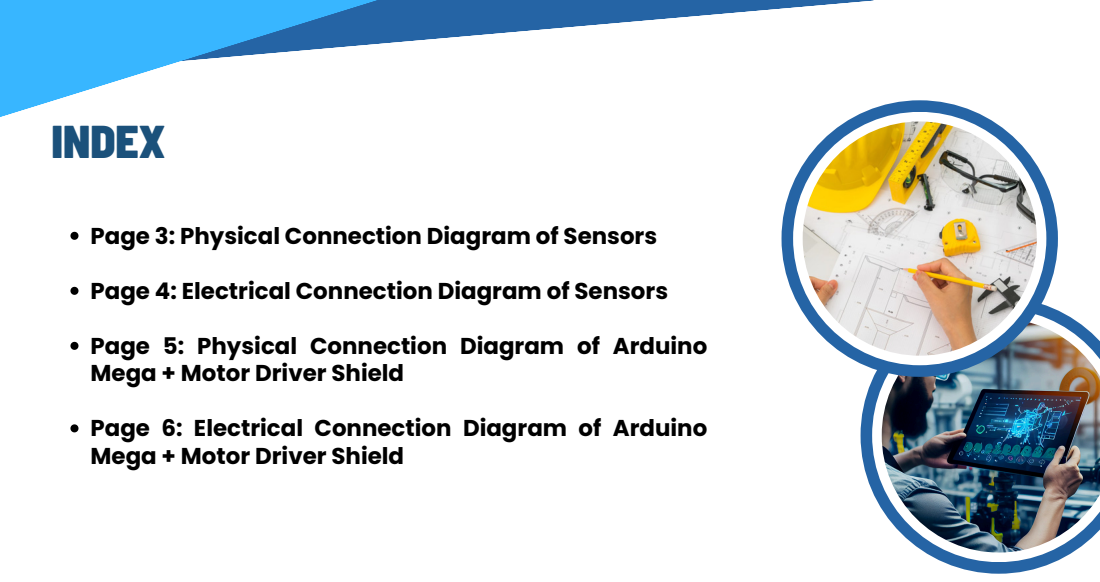
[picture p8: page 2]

Page 3: Physical Connection Diagram of Sensors
Page 4: Electrical Connection Diagram of Sensors
Page 5: Physical Connection Diagram of Arduino
Mega + Motor Driver Shield
Page 6: Electrical Connection Diagram of Arduino

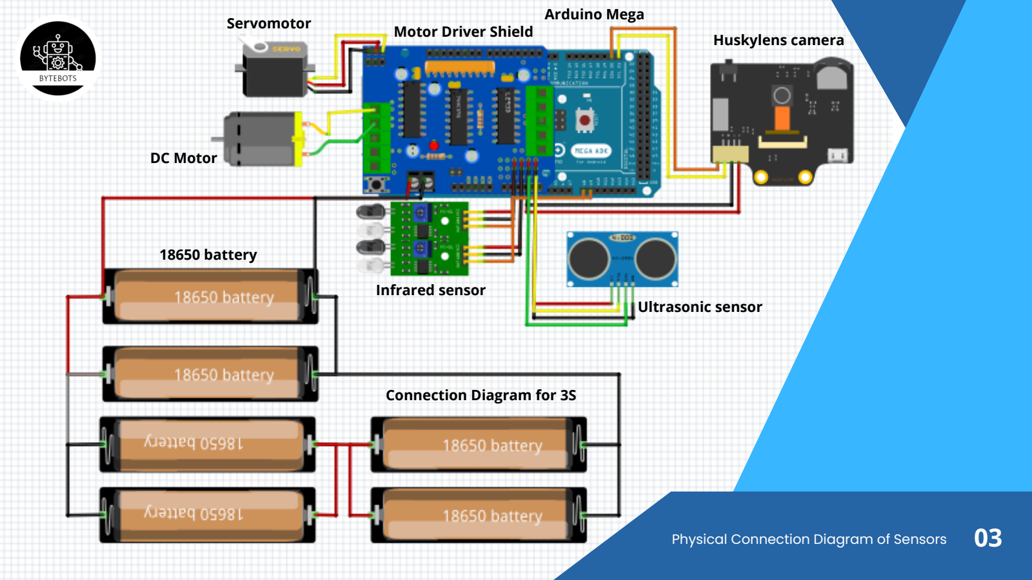
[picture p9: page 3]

Connection Diagram for 3S

Infrared sensor
Ultrasonic sensor

Huskylens camera

Servomotor

DC Motor

Motor Driver Shield

Arduino Mega

18650 battery

Physical Connection Diagram of Sensors 03

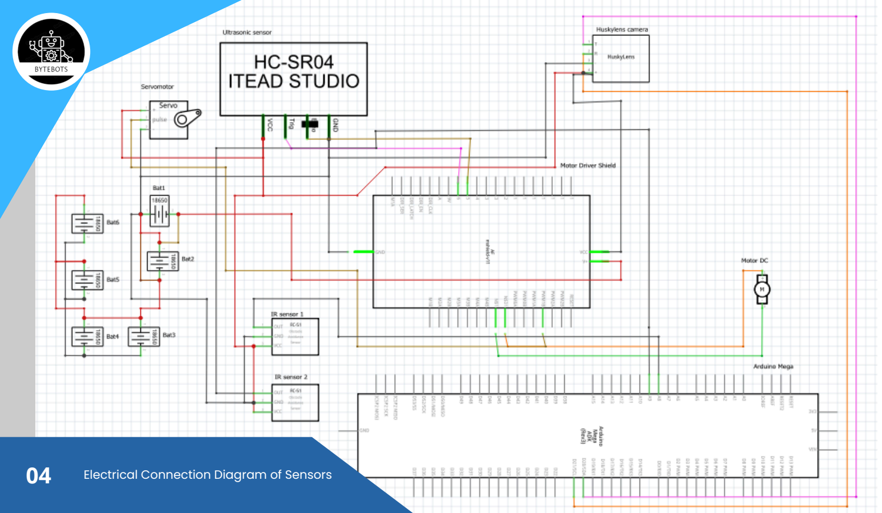
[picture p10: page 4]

### 04 Electrical Connection Diagram of Sensors

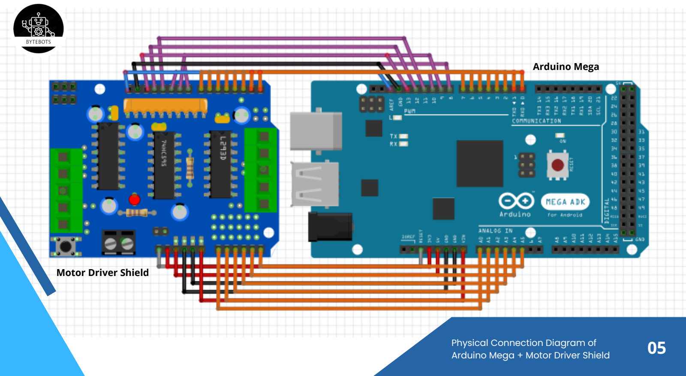
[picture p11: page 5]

05

Arduino Mega

Motor Driver Shield

Physical Connection Diagram of Arduino Mega + Motor Driver Shield

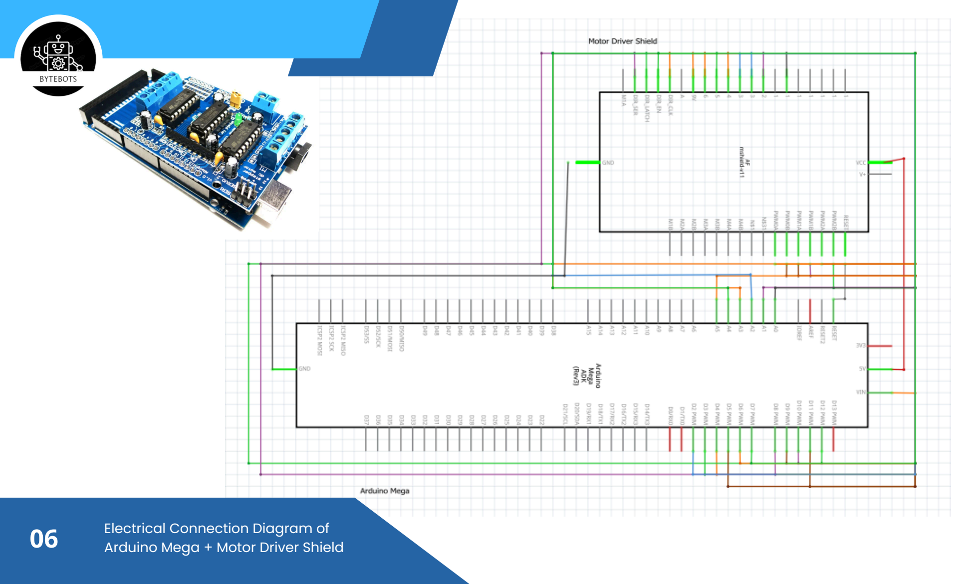
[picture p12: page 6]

06

Electrical Connection Diagram of Arduino Mega + Motor Driver Shield

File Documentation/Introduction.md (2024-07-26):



# ByteBots Team Repository for the Competition WRO 🤖

This repository contains all the documentation, source code, schematics, and resources related to the robot developed by the ByteBots team for the WRO competition, categorized as "Future Engineers".

## Team Members

<!-- Anthony-->

<details>
<summary>
Anthony Vargas 🛠️
</summary>

<div style="padding: 10px; border: 1px solid #ddd; border-radius: 5px; background-color: #f9f9f9; margin-bottom: 10px;">
    <h3>About Me</h3>
    <p>
        Soy un apasionado desarrollador con experiencia en diversas tecnologías y herramientas. Me encanta aprender y aplicar nuevas técnicas para resolver problemas y construir soluciones innovadoras.
    </p>
</div>

<h3>Languages</h3>
<p>
    <div align="left">
        C++
        Python
    </div>
</p>

<h3>Platforms</h3>
<p>
    <div style="display: flex; align-items: center; flex-wrap: wrap;">
        Arduino
        Linux
        Ubuntu
    </div>
</p>

<h3>Contact</h3>
<p>
    <a href="https://www.instagram.com/antthonyyyy_999?utm_source=ig_web_button_share_sheet&igsh=ZDNlZDc0MzIxNw==" target="blank">
        Anthony Vargas Instagram
    </a>
</p>

<hr width="36%" >
 
</details>

<!-- Yonathan -->
  
<details>
<summary>
Yonathan González 👨‍💻
</summary>

<div style="padding: 10px; border: 1px solid #ddd; border-radius: 5px; background-color: #f9f9f9; margin-bottom: 10px;">
    <h3>About Me</h3>
    <p>
        Soy un apasionado desarrollador con experiencia en diversas tecnologías y herramientas. Me encanta aprender y aplicar nuevas técnicas para resolver problemas y construir soluciones innovadoras.
    </p>
</div>

<h3>Languages</h3>
<p>
    <div align="left">
    C++
    Dart
    HTML
</div>

</p>

<h3>Platforms</h3>
<p>
    <div style="display: flex; align-items: center; flex-wrap: wrap;">
    Arduino
    Firebase
    Flutter
    Github
    GCP
    VSCode
</div>

</p>

<h3>Contact</h3>
<p>
    <a href="https://www.linkedin.com/in/yonathan-gonzalez/" target="blank">
    Yonathan Gonzalez LinkedIn
</a>
<a href="https://www.instagram.com/yonthan_gonzalez/" target="blank">
    Yonathan Gonzalez Instagram
</a>

</p>

 <hr width="36%" >
 
</details>

 <!-- Miguelangel -->
 
- Miguelangel Moreno 📊
  
👩‍💼 Coordinator: Vianca Cuevas

🌟 Sponsored by **Rincón Clubhouse La Chorrera** 🇵🇦

## Team Nature

🤖 We are an independent team passionate about robotics and innovation. 🚀

---

# Repositorio del Equipo ByteBots para la Competencia WRO 🤖

Este repositorio contiene toda la documentación, código fuente, esquemas y recursos relacionados con el robot desarrollado por el equipo ByteBots para la competencia WRO, bajo la categoría de "Futuros ingenieros".

## Miembros del Equipo

<!-- Anthony-->

<details>
<summary>
Anthony Vargas 🛠️
</summary>

<div style="padding: 10px; border: 1px solid #ddd; border-radius: 5px; background-color: #f9f9f9; margin-bottom: 10px;">
    <h3>About Me</h3>
    <p>
        Soy un apasionado desarrollador con experiencia en diversas tecnologías y herramientas. Me encanta aprender y aplicar nuevas técnicas para resolver problemas y construir soluciones innovadoras.
    </p>
</div>

<h3>Languages</h3>
<p>
    <div align="left">
        C++
        Python
    </div>
</p>

<h3>Platforms</h3>
<p>
    <div style="display: flex; align-items: center; flex-wrap: wrap;">
        Arduino
        Linux
        Ubuntu
    </div>
</p>

<h3>Contact</h3>
<p>
    <a href="https://www.instagram.com/antthonyyyy_999?utm_source=ig_web_button_share_sheet&igsh=ZDNlZDc0MzIxNw==" target="blank">
        Anthony Vargas Instagram
    </a>
</p>

<hr width="36%" >
 
</details>

<!-- Yonathan -->
  
<details>
<summary>
Yonathan González 👨‍💻
</summary>

<div style="padding: 10px; border: 1px solid #ddd; border-radius: 5px; background-color: #f9f9f9; margin-bottom: 10px;">
    <h3>About Me</h3>
    <p>
        Soy un apasionado desarrollador con experiencia en diversas tecnologías y herramientas. Me encanta aprender y aplicar nuevas técnicas para resolver problemas y construir soluciones innovadoras.
    </p>
</div>

<h3>Languages</h3>
<p>
    <div align="left">
    C++
    Dart
    HTML
</div>

</p>

<h3>Platforms</h3>
<p>
    <div style="display: flex; align-items: center; flex-wrap: wrap;">
    Arduino
    Firebase
    Flutter
    Github
    GCP
    VSCode
</div>

</p>

<h3>Contact</h3>
<p>
    <a href="https://www.linkedin.com/in/yonathan-gonzalez/" target="blank">
    Yonathan Gonzalez LinkedIn
</a>
<a href="https://www.instagram.com/yonthan_gonzalez/" target="blank">
    Yonathan Gonzalez Instagram
</a>

</p>

 <hr width="36%" >
 
</details>

 <!-- Miguelangel -->
 
- Miguelangel Moreno 📊
  
👩‍💼 Coordinadora: Vianca Cuevas

🌟 Patrocinado por **Rincón Clubhouse La Chorrera** 🇵🇦

## Naturaleza del Equipo

🤖 Somos un equipo independiente apasionado por la robótica y la innovación. 🚀

---

## Partners

<div align="left">
    <a href="https://rinconesclubhouse.org/">
        Rincones Clubhouse 1
    </a>
    <a href="https://rinconesclubhouse.org/">
        Rincones Clubhouse 2
    </a>
</div>

<div align="center">
    <a href="https://www.linkedin.com/company/rinconesclubhousepanama/">
        LinkedIn
    </a>
    <a href="https://www.instagram.com/rclubhouselachorrera?utm_source=ig_web_button_share_sheet&igsh=ZDNlZDc0MzIxNw==">
        Instagram
    </a>
    <a href="https://www.youtube.com/@rinconclubhouselachorrera3136">
        YouTube
    </a>
</div>

---

<div align="center">

<p style="font-size: 20px; color: #555; font-weight: bold; text-shadow: 1px 1px 2px rgba(0, 0, 0, 0.3);">
Made with ❤️ by Bytebots Team
</p>

</div>

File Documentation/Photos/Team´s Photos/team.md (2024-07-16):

# ByteBot Project Team

## Meet Our Team

Our team is comprised of three dedicated and skilled individuals, each bringing their unique expertise to the project:

- **Anthony Vargas** (19 years old): Anthony serves as our assembler 🔧, responsible for assembling Arduino components. His meticulous attention to detail and practical experience in hardware assembly ensure that all components are correctly connected and functioning.

- **Yonathan González** (19 years old): Yonathan is our lead programmer 👨‍💻, responsible for writing the code that drives our project and ensures seamless functionality. His profound knowledge of programming languages and his problem-solving skills make him an invaluable asset to the team.

- **Miguelangel Moreno** (17 years old): Miguelangel designs our connection diagrams 📊. His ability to create clear and precise schematics ensures that our wiring is efficient and error-free. His creativity and technical skills simplify complexity and enhance understanding.

### LinkedIn Profiles:

- [Yonathan González LinkedIn Profile](https://www.linkedin.com/in/yonathan-gonzalez/)

### Team Dynamics

- **Collaborative Decision-Making**: All decisions are made collectively, ensuring that each team member's perspective and expertise contribute to the final outcome. This approach fosters a sense of unity and shared responsibility.

- **Mastery in Assigned Roles**: Each member has a high degree of mastery in their respective roles, which guarantees the quality and efficiency of our project. 

- **Cross-Functional Skills**: While each member has their primary role, all three possess skills in the other areas as well. This cross-training ensures that our project remains on track even if one member needs to step into another role temporarily. This adaptability is crucial for maintaining our project’s momentum and resilience.

### Cool Aspects of Our Team

**Innovation** 🚀: We constantly explore new ideas and technologies to integrate into our project. Our passion for learning and innovation drives us to push the boundaries of what we can achieve.

**Commitment to Quality** ⭐: We are committed to delivering a high-quality product. Our attention to detail and thorough testing processes ensure that our project not only works but excels in its performance.

**Team Spirit** 👥: Our strong team spirit and mutual respect for each other's skills and contributions make working together both productive and enjoyable. We believe that a positive team dynamic is key to overcoming challenges and achieving our goals.

---

# Equipo del Proyecto ByteBot

## Conozca a Nuestro Equipo

Nuestro equipo está compuesto por tres individuos dedicados y hábiles, cada uno aportando su experiencia única al proyecto:

- **Anthony Vargas** (19 años): Anthony es nuestro ensamblador 🔧, responsable de ensamblar los componentes de Arduino. Su meticulosa atención al detalle y su experiencia práctica en el ensamblaje de hardware aseguran que todos los componentes estén correctamente conectados y funcionando.

- **Yonathan González** (19 años): Yonathan es nuestro programador principal 👨‍💻, encargado de escribir el código que impulsa nuestro proyecto y garantiza su funcionalidad sin problemas. Su profundo conocimiento de los lenguajes de programación y sus habilidades para resolver problemas lo convierten en un activo invaluable para el equipo.

- **Miguelangel Moreno** (17 años): Miguelangel diseña nuestros diagramas de conexión 📊. Su capacidad para crear esquemas claros y precisos asegura que nuestro cableado sea eficiente y libre de errores. Su creatividad y habilidades técnicas simplifican la complejidad y mejoran la comprensión.

### Perfiles de LinkedIn:

- [Perfil de LinkedIn de Yonathan González](https://www.linkedin.com/in/yonathan-gonzalez/)

### Dinámica del Equipo

- **Toma de Decisiones Colaborativa**: Todas las decisiones se toman en conjunto, asegurando que la perspectiva y la experiencia de cada miembro contribuyan al resultado final. Este enfoque fomenta un sentido de unidad y responsabilidad compartida.

- **Maestría en Roles Asignados**: Cada miembro tiene un alto grado de maestría en sus respectivos roles, lo que garantiza la calidad y eficiencia de nuestro proyecto.

- **Habilidades Multifuncionales**: Aunque cada miembro tiene su rol principal, los tres poseen habilidades en las otras áreas también. Esta capacitación cruzada asegura que nuestro proyecto se mantenga en marcha incluso si un miembro necesita asumir temporalmente otro rol. Esta adaptabilidad es crucial para mantener el impulso y la resiliencia de nuestro proyecto.

### Aspectos Geniales de Nuestro Equipo

**Innovación** 🚀: Constantemente exploramos nuevas ideas y tecnologías para integrar en nuestro proyecto. Nuestra pasión por el aprendizaje y la innovación nos impulsa a ampliar los límites de lo que podemos lograr.

**Compromiso con la Calidad** ⭐: Estamos comprometidos con entregar un producto de alta calidad. Nuestra atención al detalle y nuestros procesos exhaustivos de prueba aseguran que nuestro proyecto no solo funcione, sino que sobresalga en su rendimiento.

**Espíritu de Equipo** 👥: Nuestro fuerte espíritu de equipo y el respeto mutuo por las habilidades y contribuciones de cada miembro hacen que trabajar juntos sea tanto productivo como placentero. Creemos que una dinámica de equipo positiva es clave para superar desafíos y alcanzar nuestros objetivos.

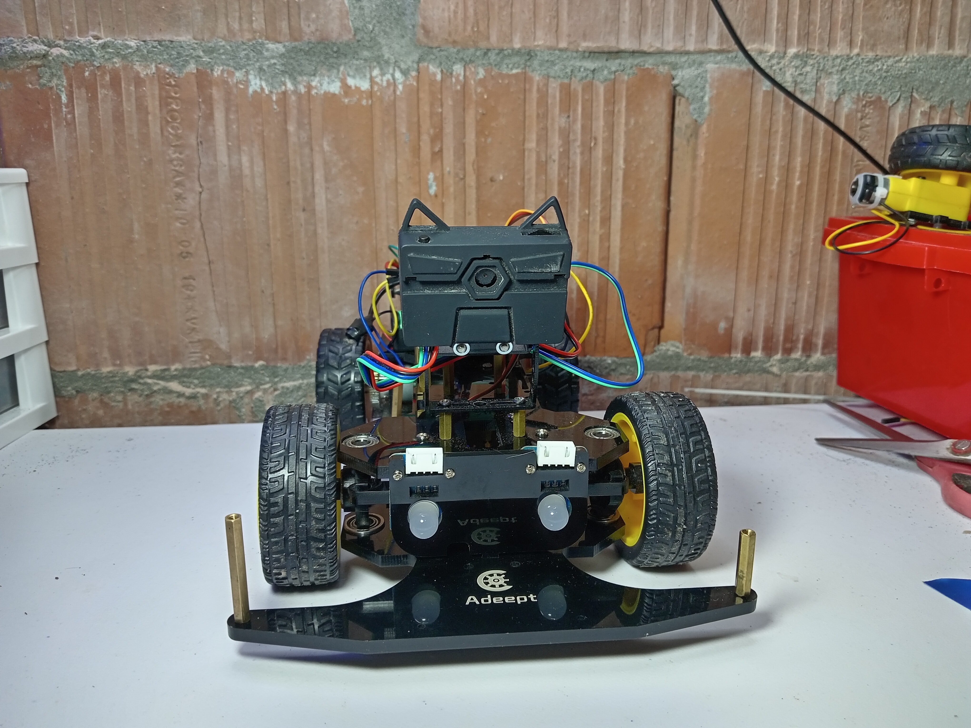
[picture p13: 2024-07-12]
Documentation/Photos/Vehicle's photos/Lado frontal.jpg

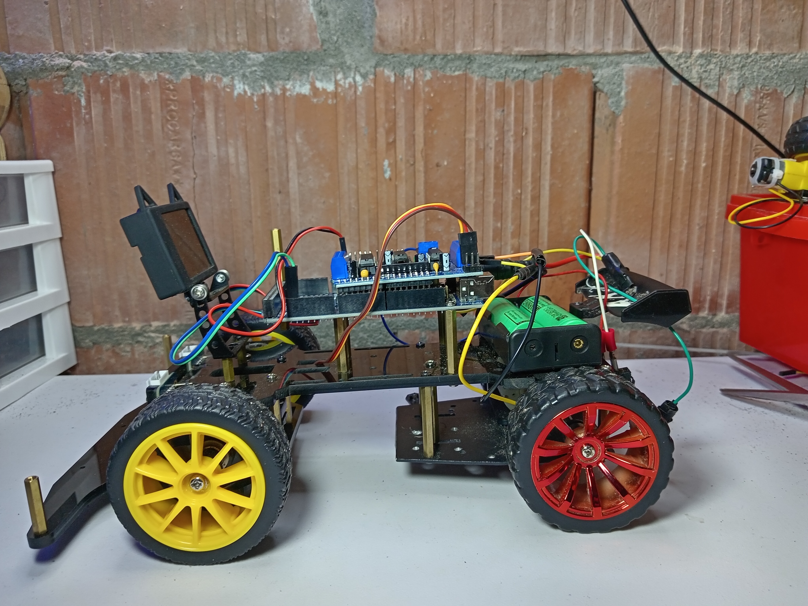
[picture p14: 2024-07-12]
Documentation/Photos/Vehicle's photos/Lado derecho.jpg

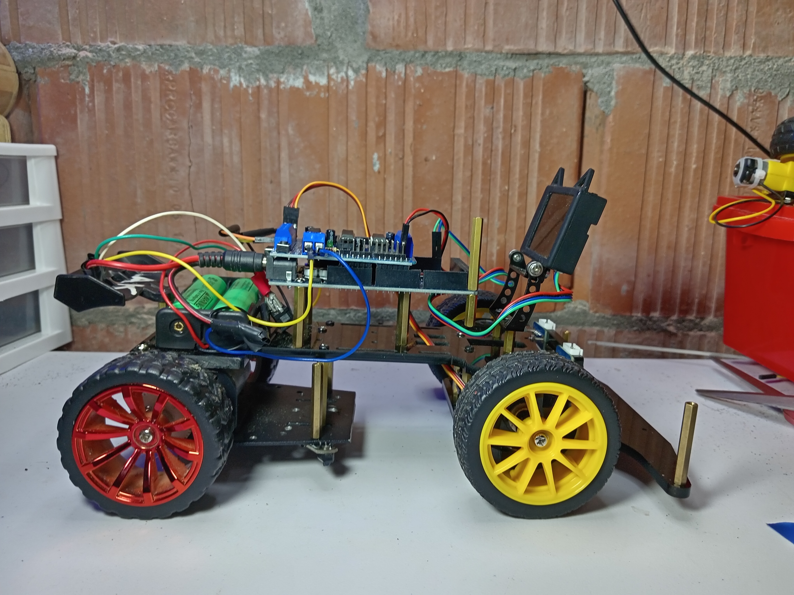
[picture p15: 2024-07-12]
Documentation/Photos/Vehicle's photos/Lado izquierdo.jpg

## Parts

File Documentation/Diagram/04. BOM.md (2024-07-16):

# Diagrama de Cableado y Lista de Materiales (BOM)

## Diagrama de Cableado

### Diagrama Físico

El diagrama físico detalla la disposición física de los componentes y sus conexiones.

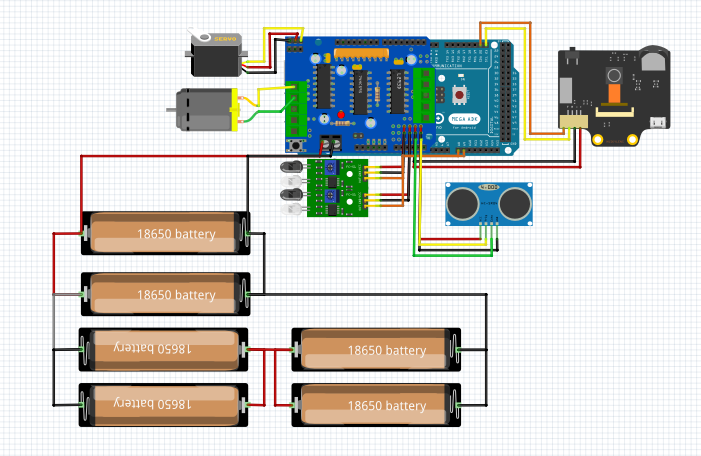
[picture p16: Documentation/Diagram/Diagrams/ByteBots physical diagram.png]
Diagrama Físico


### Diagrama Eléctrico

El diagrama eléctrico muestra las conexiones eléctricas detalladas entre los componentes.

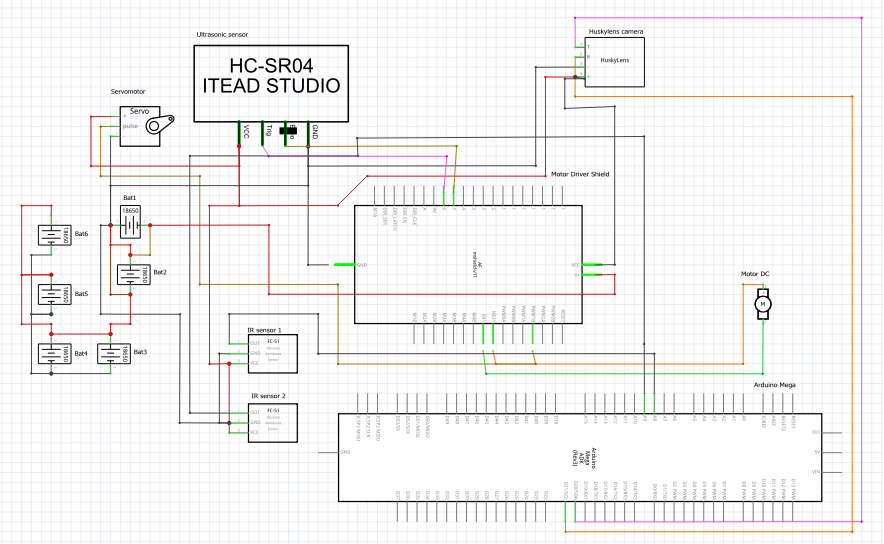
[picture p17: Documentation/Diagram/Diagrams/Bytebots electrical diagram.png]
Diagrama Eléctrico


> **Nota**: Las imágenes que visualiza están completamente descritas en el PDF Diagramas, enlace: [Diagrams PDF](https://github.com/Fredrinn/WRO-ByteBot/blob/main/Documentation/Diagram/Diagrams/Diagrams%20PDF.pdf). Todos los diagramas fueron confeccionados por el equipo de ByteBots. En caso de querer visualizar y editar los componentes, puede hacerlo mediante los documentos .fzpz dejados en el repositorio:
> 
> - [Esquema ByteBots - Motor Driver Shield + Arduino Mega](https://github.com/Fredrinn/WRO-ByteBot/blob/main/Documentation/Diagram/Diagrams/Esquema%20ByteBots%20-%20Motor%20Driver%20Shield%20%2B%20Arduino%20Mega.fzz)
> - [Esquema Bytebots](https://github.com/Fredrinn/WRO-ByteBot/blob/main/Documentation/Diagram/Diagrams/Esquema_Bytebots.fzz)
> 
> La plataforma utilizada es Fritzing: [Fritzing](https://fritzing.org/), que se puede descargar desde: [Descargar Fritzing](https://fritzing.org/download/).

## Lista de Materiales (BOM)

### Componentes Principales

1. **Placa Arduino Mega 2560**
   - Controlador principal del sistema.
   - [Enlace al Producto](https://a.co/d/ckFzcAl)
   - Cantidad: 1 unidad

2. **Módulo Driver de Motores L298N**
   - Controla motores de corriente continua y servomotores.
   - [Enlace al Producto](https://a.co/d/bUoIC6j)
   - Cantidad: 1 unidad

3. **Baterías 18650**
   - Fuente de alimentación principal.
   - [Enlace al Producto](https://a.co/d/cmlgMsl)
   - Cantidad: 6 unidades

4. **Sensor Ultrasónico HC-SR04**
   - Utilizado para medir distancias.
   - [Enlace al Producto](https://a.co/d/f0cdoob)
   - Cantidad: 1 unidad

5. **Módulo Sensor IR (Infrarrojo)**
   - Detecta obstáculos cercanos.
   - [Enlace al Producto](https://a.co/d/0LpqT3M)
   - Cantidad: 1 unidad

6. **Módulo Cámara**
   - Captura imágenes para procesamiento visual.
   - [Enlace al Producto](https://a.co/d/5XpMI4a)
   - Cantidad: 1 unidad

### Cables y Conectores

1. **Cables Dupont**
   - Para conexiones internas entre componentes.
   - [Enlace al Producto](https://a.co/d/6Gw2NZg)
   - Cantidad: 10 unidades

2. **Cables de Alimentación**
   - Para conectar las baterías y distribuir la energía.
   - Cantidad: 1 juego

### Otros Materiales

1. **Kit Model A**
   - [Enlace al Producto](https://a.co/d/6iml1Xq)
   - Cantidad: 1 kit

2. **Kit Model B**
   - [Enlace al Producto](https://bc-robotics.com/shop/2wd-metal-chassis-kit-high-speed/)
   - Cantidad: 1 kit

## Instrucciones de Ensamblaje 🤖🔧🔋📷

### 1. Conectar el Motor Driver Shield al Arduino Mega

- Alinea el Motor Driver Shield sobre el Arduino Mega, asegurando una alineación perfecta de los pines. 💡
- Presiona firmemente el Shield hasta que encaje sin necesidad de herramientas. 🛠️
- Si algunos pines sobresalen, dóblalos con cuidado para evitar interferencias con otras conexiones. ⚙️

### 2. Preparar las Baterías 18650

- Conecta las 6 baterías 18650 en serie usando cables dupont para unir los terminales positivos y negativos. 🔋
- Soldar las conexiones aumenta la seguridad y evita cortocircuitos. 🛠️
- Asegúrate de mantener la polaridad correcta durante la conexión.

### 3. Conectar el Sensor Ultrasónico HC-SR04

- VCC del sensor al pin 5V del Motor Driver Shield.
- GND del sensor al pin GND del Motor Driver Shield.
- Trig del sensor al pin D11 del Arduino Mega.
- Echo del sensor al pin D12 del Arduino Mega. 📏

### 4. Conectar la Cámara HuskyLens

- 5V de la cámara al pin 5V del Motor Driver Shield.
- GND de la cámara al pin GND del Motor Driver Shield.
- SCL de la cámara al pin SCL del Arduino Mega.
- SDA de la cámara al pin SDA del Arduino Mega.
- I2C_EN de la cámara al pin D2 del Arduino Mega. 📷

### 5. Conectar los Motores DC

- Cable rojo del motor DC 1 al terminal M1 del Motor Driver Shield.
- Cable negro del motor DC 1 al terminal GND del Motor Driver Shield.
- Cable rojo del motor DC 2 al terminal M2 del Motor Driver Shield.
- Cable negro del motor DC 2 al terminal GND del Motor Driver Shield. ⚙️

### 6. Montar los Componentes en el Chasis del Robot

- Fija el Arduino Mega con el Motor Driver Shield en el chasis usando tornillos o cinta adhesiva de doble cara. 🛠️
- Posiciona estratégicamente la cámara HuskyLens y el sensor ultrasónico para optimizar su funcionalidad. 📏

### 7. Cargar y Configurar el Código en el Arduino Mega

- Descarga el IDE de Arduino desde [este enlace](https://www.arduino.cc/en/software) si aún no lo tienes.
- Descarga las librerías necesarias desde [aquí](https://github.com/Fredrinn/WRO-ByteBot/tree/main/Documentation/Code/Libraries).
- Si necesitas ayuda para instalar una librería, consulta la documentación oficial de Arduino [aquí](https://docs.arduino.cc/software/ide-v1/tutorials/installing-libraries/). 🖥️

### 8. Prueba y Calibración del Robot

- Enciende el sistema y verifica que todos los componentes respondan correctamente.
- Prueba los motores DC para asegurarte de que funcionen según lo esperado.
- Verifica la precisión del sensor ultrasónico y realiza pruebas con la cámara HuskyLens para confirmar la captura y procesamiento de imágenes o vídeos. 🚀📸

Esta guía te proporciona instrucciones claras y detalladas para ensamblar y configurar tu robot avanzado, asegurando un montaje seguro y funcional para aplicaciones de robótica y visión artificial.

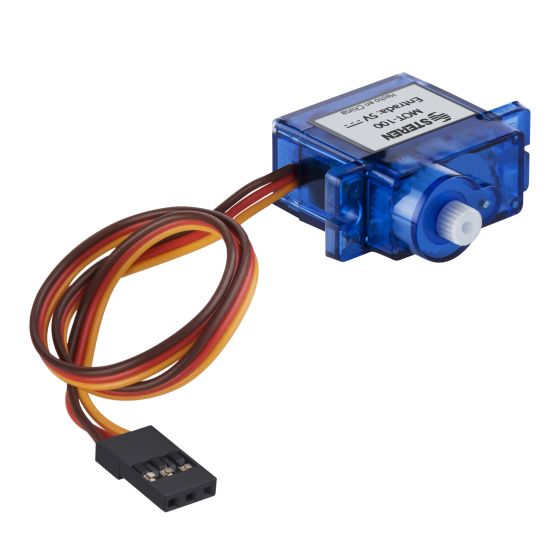
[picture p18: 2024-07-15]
Documentation/Diagram/Component/micro-servomotor.jpg

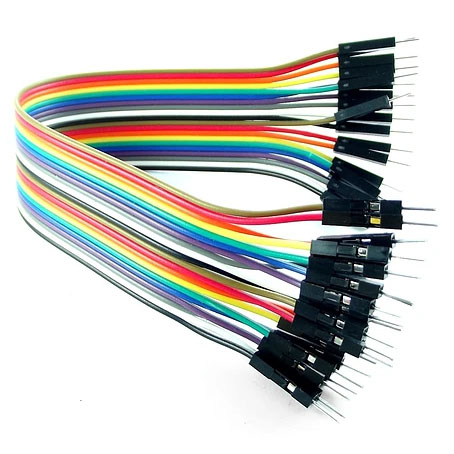
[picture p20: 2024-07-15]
Documentation/Diagram/Component/Cables-Dupont.jpg

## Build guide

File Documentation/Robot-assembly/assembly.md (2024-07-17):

### Robot Description

Our robot has been assembled using components from various robotics kits, strategically chosen to optimize spatial distribution and system functionality. This technical decision was driven by the need to integrate a variety of sensors and actuators, while adhering to competition specifications and constraints.

The combination of these kits enabled a modular and adaptable design, facilitating the incorporation of diverse electronic and mechanical components. We prioritized efficiency in arranging these elements, ensuring a coherent and functional interface among sensors, motors, and the central control system.

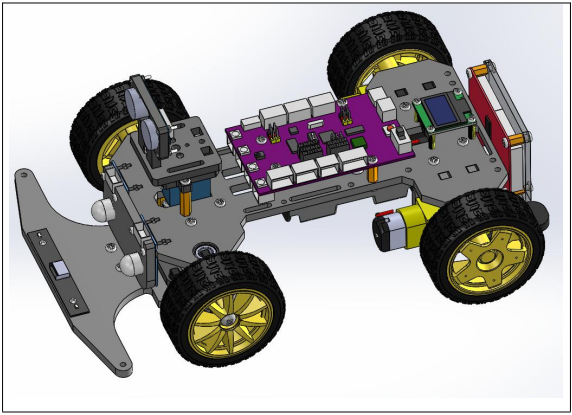
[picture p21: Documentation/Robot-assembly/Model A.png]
Model A
<br>
**Model A**

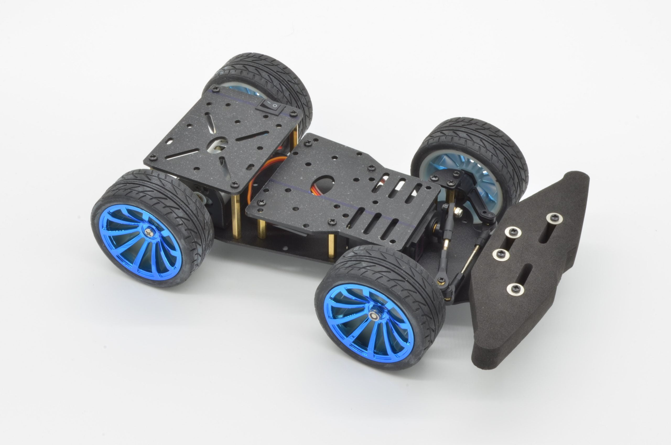
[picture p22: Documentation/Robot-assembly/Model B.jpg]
Model B
<br>
**Model B**

> **Note:**
> 
> The PDF files "Assemble Model A" and "Assemble Model B" detail the assembly of the final models. Components such as sensors were specifically selected to suit our needs. We decided not to use sensors and components provided in standard kits, such as programming boards and motors, instead opting for those we considered most suitable for our technical requirements and project objectives.
> 
> This integration approach has resulted in a final prototype that not only meets the technical requirements but also maximizes the robot's performance and reliability.

---

### Descripción del Robot

Nuestro robot ha sido ensamblado utilizando componentes provenientes de diferentes kits de robótica, seleccionados estratégicamente para optimizar la distribución espacial y funcionalidad del sistema. Esta decisión técnica se basó en la necesidad de integrar una variedad de sensores y actuadores, respetando las especificaciones y restricciones impuestas por las normativas de la competencia.

La combinación de estos kits permitió un diseño modular y adaptable, facilitando la incorporación de diversos componentes electrónicos y mecánicos. Se priorizó la eficiencia en la disposición de los elementos, asegurando una interfaz coherente y funcional entre los sensores, motores y el sistema de control central.

Model A<br>
**Modelo A**

Model B<br>
**Modelo B**

> **Nota:**
> 
> Los archivos PDF "Assemble Model A" y "Assemble Model B" detallan el ensamblaje de los modelos finales. Los componentes, como sensores, fueron seleccionados específicamente para adaptarse a nuestras necesidades. Decidimos no utilizar sensores y componentes proporcionados en kits estándar, como placas de programación y motores, optando en su lugar por aquellos que consideramos más adecuados para nuestros requisitos técnicos y objetivos del proyecto.
> 
> Este enfoque de integración ha resultado en un prototipo final que no solo cumple con los requisitos técnicos, sino que también maximiza el rendimiento y la confiabilidad del robot.

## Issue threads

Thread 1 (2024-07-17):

Gestión de Movilidad

Fredrinn, 2024-07-17:
- [ ] Discutir la gestión de movimientos del vehículo
- [ ] Seleccionar e implementar motores
- [ ] Diseñar o seleccionar el chasis del vehículo
- [ ] Crear instrucciones de construcción o archivos CAD 3D para imprimir piezas

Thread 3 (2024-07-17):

Gestión de Energía y Sensores

Fredrinn, 2024-07-17:
- [ ] Cobertura de la fuente de alimentación y los sensores
- [ ] Seleccionar y justificar el uso de diversos sensores
- [ ] Crear un diagrama de cableado y una lista de materiales (BOM)
- [ ] Preparar un diagrama de cableado detallado
- [ ] Elaborar la lista de materiales (BOM)

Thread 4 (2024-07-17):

Gestión de Obstáculos

Fredrinn, 2024-07-17:
- [ ] Desarrollar una estrategia para superar obstáculos
- [ ] Crear diagramas de flujo y pseudocódigo para la estrategia
- [ ] Escribir código fuente con comentarios detallados

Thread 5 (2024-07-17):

Fotos - Equipo y Vehículo

Fredrinn, 2024-07-17:
- [ ] Tomar fotos claras y enfocadas de todos los lados del robot
- [ ] Incluir aspectos de la gestión de movilidad, energía, sensores y obstáculos en las fotos

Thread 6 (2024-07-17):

Videos de Rendimiento

Fredrinn, 2024-07-17:
- [ ] Grabar videos que demuestren el rendimiento del vehículo para cada desafío
- [ ] Incluir superposiciones de comentarios, títulos o animaciones en los videos

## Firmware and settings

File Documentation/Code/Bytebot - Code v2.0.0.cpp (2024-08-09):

/*
   Código del robot ByteBot del equipo ByteBots.

   Autores: Anthony Vargas - Yonathan González.
   ________________________________________________________

   ByteBot robot code by team ByteBots.

   Authors: Anthony Vargas - Yonathan Gonzalez.
*/

// Se incluyen las librerías necesarias para el control de motores, servos y la comunicación I2C
#include <Wire.h>                     // Librería para comunicación I2C
#include <Servo.h>                    // Librería para controlar servomotores
#include <AFMotor.h>                  // Librería para controlar motores con Adafruit Motor Shield

// Se definen las constantes para los pines del servo y el sensor ultrasónico
const int pinServo = 9;               // Pin donde está conectado el servo
const int posCentro = 80;             // Posición central del servo, usada como referencia para avanzar en línea recta
const int posGiro = 100;              // Posición del servo para realizar giros, moviendo la dirección del robot
const int posRetroceso = 50;          // Posición del servo para retroceder, girando en dirección contraria
const int triggerPin = 17;            // Pin Trigger del sensor ultrasónico, envía pulsos ultrasónicos
const int echoPin = 18;               // Pin Echo del sensor ultrasónico, recibe los pulsos reflejados

// Se definen las variables para el control de velocidad del motor y las distancias para maniobras
int velocidadMotor = 170;             // Velocidad inicial del motor, valor base para empezar a moverse
const int velocidadIncremento = 10;   // Incremento de la velocidad del motor en cada ajuste
const int velocidadMaxima = 200;      // Velocidad máxima permitida para el motor, límite superior de velocidad
const int velocidadMinima = 150;      // Velocidad mínima permitida para el motor, límite inferior de velocidad
const int distanciaUmbral = 70;       // Distancia en cm para hacer el giro, evita colisiones
const int distanciaRetroceso = 35;    // Distancia en cm para retroceder, activa la maniobra de retroceso

// Se crean los objetos para controlar el motor y el servo
AF_DCMotor motor1(1);                 // Motor conectado al puerto M1 del Adafruit Motor Shield
Servo servo;                          // Objeto Servo para controlar el servomotor

void setup() {
    Serial.begin(115200);             // Inicializa la comunicación serie a 115200 baudios para depuración
    Wire.begin();                     // Inicializa la comunicación I2C, necesaria para el sensor HUSKYLENS y otros dispositivos I2C

    servo.attach(pinServo);           // Conecta el servo al pin definido anteriormente
    servo.write(posCentro);           // Inicializa el servo en la posición central para avanzar en línea recta
    motor1.setSpeed(velocidadMotor);  // Establece la velocidad inicial del motor, utilizando el valor predefinido

    pinMode(triggerPin, OUTPUT);      // Configura el pin del trigger como salida para enviar pulsos ultrasónicos
    pinMode(echoPin, INPUT);          // Configura el pin del echo como entrada para recibir los pulsos reflejados
}

void loop() {
    long duracion, distancia;         // Variables para almacenar la duración del pulso y la distancia calculada

    // Realiza una medición con el sensor ultrasónico, enviando un pulso y midiendo el tiempo de retorno
    digitalWrite(triggerPin, LOW);    // Asegura que el trigger esté en bajo antes de enviar el pulso
    delayMicroseconds(2);             // Espera 2 microsegundos para estabilizar la señal
    digitalWrite(triggerPin, HIGH);   // Activa el trigger para enviar un pulso ultrasónico
    delayMicroseconds(10);            // Mantiene el pulso durante 10 microsegundos
    digitalWrite(triggerPin, LOW);    // Desactiva el trigger, finalizando el pulso

    duracion = pulseIn(echoPin, HIGH); // Mide el tiempo en microsegundos que tarda en recibir el eco del pulso
    distancia = (duracion / 2) / 29.1; // Convierte la duración del pulso en distancia en centímetros

    // Muestra la distancia medida en el monitor serial para fines de depuración
    Serial.print("Distancia: ");
    Serial.print(distancia);
    Serial.println(" cm");

    // Ajusta la velocidad del motor en función de la distancia medida
    if (distancia <= distanciaRetroceso) {
        // Si el objeto está muy cerca, a 35 cm o menos, activa la maniobra de retroceso
        servo.write(posRetroceso);    // Mueve el servo a la posición de retroceso para cambiar de dirección
        motor1.setSpeed(velocidadMotor); // Mantiene la velocidad actual del motor
        motor1.run(BACKWARD);         // Invierte la dirección del motor para retroceder
        delay(1000);                  // Mantiene el retroceso durante 1 segundo
        motor1.run(RELEASE);          // Detiene el motor después del retroceso
        servo.write(posCentro);       // Regresa el servo a la posición central para preparar el avance
        delay(500);                   // Espera medio segundo para estabilizar el servo antes de continuar
        return;                       // Finaliza el ciclo actual para evitar avanzar de inmediato
    } else if (distancia < distanciaUmbral) {
        // Si el objeto está dentro del umbral de 70 cm pero no tan cerca como para retroceder
        velocidadMotor -= velocidadIncremento; // Disminuye la velocidad del motor para evitar colisiones
        if (velocidadMotor < velocidadMinima) velocidadMotor = velocidadMinima; // Limita la velocidad mínima
        motor1.setSpeed(velocidadMotor); // Actualiza la velocidad del motor con el nuevo valor reducido
    } else {
        // Si no hay objetos cercanos, aumenta la velocidad del motor para avanzar más rápido
        velocidadMotor += velocidadIncremento; // Incrementa la velocidad del motor para aprovechar la distancia libre
        if (velocidadMotor > velocidadMaxima) velocidadMotor = velocidadMaxima; // Limita la velocidad máxima
        motor1.setSpeed(velocidadMotor); // Actualiza la velocidad del motor con el nuevo valor incrementado
    }

    motor1.run(FORWARD);              // Avanza el motor hacia adelante con la velocidad ajustada

    // Realiza el giro si la distancia medida es menor que el umbral definido
    if (distancia < distanciaUmbral) {
        servo.write(posGiro);         // Gira el servo a la posición de giro para cambiar la dirección del robot
        delay(2000);                  // Mantiene el giro durante 2 segundos para completar la maniobra
        servo.write(posCentro);       // Regresa el servo a la posición central para continuar avanzando recto
        delay(1000);                  // Espera 1 segundo para estabilizar el servo después del giro
    }

    delay(100);                       // Espera un corto tiempo antes de realizar la siguiente medición de distancia
}

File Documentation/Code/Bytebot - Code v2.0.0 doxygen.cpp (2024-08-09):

/**
 * @file ByteBot.cpp
 * @brief Código de control para el robot ByteBot del equipo ByteBots.
 * 
 * Este código controla el movimiento de un robot utilizando un motor DC y un servo. 
 * El robot ajusta su velocidad y dirección en función de la distancia medida por un sensor ultrasónico.
 * 
 * @authors Anthony Vargas
 * @authors Yonathan González
 * @version 1.0
 * @date 2024
 */

// Incluye las librerías necesarias
#include <Wire.h>
#include <Servo.h>
#include <AFMotor.h>

/** @brief Pin de conexión del servo motor */
const int pinServo = 9;

/** @brief Posición central del servo motor */
const int posCentro = 80;

/** @brief Posición del servo motor al girar */
const int posGiro = 100;

/** @brief Posición del servo motor para retroceso */
const int posRetroceso = 50;

/** @brief Pin Trigger del sensor ultrasónico */
const int triggerPin = 17;

/** @brief Pin Echo del sensor ultrasónico */
const int echoPin = 18;

/** @brief Velocidad inicial del motor */
int velocidadMotor = 170;

/** @brief Incremento de la velocidad del motor */
const int velocidadIncremento = 10;

/** @brief Velocidad máxima del motor */
const int velocidadMaxima = 200;

/** @brief Velocidad mínima del motor */
const int velocidadMinima = 150;

/** @brief Distancia umbral en cm para hacer el giro */
const int distanciaUmbral = 70;

/** @brief Distancia en cm para activar el retroceso */
const int distanciaRetroceso = 35;

// Instancia del motor conectado al puerto M1
AF_DCMotor motor1(1);

// Instancia del objeto Servo
Servo servo;

/**
 * @brief Configuración inicial del sistema.
 * 
 * Configura los pines de entrada/salida, inicializa la comunicación serial e I2C, 
 * y establece la posición inicial del servo y la velocidad del motor.
 */
void setup() {
    Serial.begin(115200);          // Inicializa la comunicación serie a 115200 baudios
    Wire.begin();                  // Inicializa la comunicación I2C

    servo.attach(pinServo);        // Conecta el servo al pin definido
    servo.write(posCentro);        // Inicializa el servo en la posición central
    motor1.setSpeed(velocidadMotor); // Establece la velocidad inicial del motor

    pinMode(triggerPin, OUTPUT);   // Configura el pin del trigger como salida
    pinMode(echoPin, INPUT);       // Configura el pin del echo como entrada
}

/**
 * @brief Función principal del sistema.
 * 
 * Lee la distancia desde el sensor ultrasónico y ajusta la velocidad y dirección 
 * del motor y la posición del servo en consecuencia.
 */
void loop() {
    long duracion, distancia;

    // Realiza una medición con el sensor ultrasónico
    digitalWrite(triggerPin, LOW);
    delayMicroseconds(2);
    digitalWrite(triggerPin, HIGH);
    delayMicroseconds(10);
    digitalWrite(triggerPin, LOW);
    duracion = pulseIn(echoPin, HIGH);
    distancia = (duracion / 2) / 29.1; // Convierte la duración a distancia en cm

    // Muestra la distancia en el monitor serial
    Serial.print("Distancia: ");
    Serial.print(distancia);
    Serial.println(" cm");

    // Ajusta la velocidad del motor según la distancia
    if (distancia <= distanciaRetroceso) {
        // Retrocede si el objeto está a 35 cm o menos
        servo.write(posRetroceso); // Gira el servo a la posición de retroceso
        motor1.setSpeed(velocidadMotor); // Mantiene la velocidad actual
        motor1.run(BACKWARD); // Retrocede el motor
        delay(1000); // Mantiene el retroceso durante 1 segundo
        motor1.run(RELEASE); // Detiene el motor
        servo.write(posCentro); // Regresa el servo a la posición central
        delay(500); // Espera medio segundo para estabilizar el servo
        return; // Salta el resto del loop
    } else if (distancia < distanciaUmbral) {
        // Reduce la velocidad si el objeto está a menos de 70 cm
        velocidadMotor -= velocidadIncremento;
        if (velocidadMotor < velocidadMinima) velocidadMotor = velocidadMinima; // Asegura que la velocidad no sea menor que la mínima
        motor1.setSpeed(velocidadMotor); // Actualiza la velocidad del motor
    } else {
        // Aumenta la velocidad si el objeto está a más de 70 cm
        velocidadMotor += velocidadIncremento;
        if (velocidadMotor > velocidadMaxima) velocidadMotor = velocidadMaxima; // Limita la velocidad a la máxima
        motor1.setSpeed(velocidadMotor); // Actualiza la velocidad del motor
    }

    motor1.run(FORWARD); // Avanza el motor

    // Realiza el giro si la distancia es menor a 70 cm
    if (distancia < distanciaUmbral) {
        servo.write(posGiro); // Gira el servo a la posición de giro
        delay(2000); // Mantiene el giro durante 2 segundos
        servo.write(posCentro); // Regresa el servo a la posición central
        delay(1000); // Espera 1 segundo para estabilizar el servo
    }

    delay(100); // Espera un momento antes de la próxima solicitud
}

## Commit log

2024-07-14 Create Robot assembly
2024-07-14 Update 2 Assemble.pdf
    Información sobre el robot original
2024-07-14 Add files via upload
    In the following PDF, you will find detailed instructions on assembling the original model of our robot. The information is sourced from the official Adeept website: http://www.adeept.com/.
    ---
    En el siguiente PDF, encontrarás instrucciones detalladas sobre cómo ensamblar el modelo original de nuestro robot. La información proviene del sitio oficial de Adeept: http://www.adeept.com/.
2024-07-14 Rename 2 Assemble.pdf to Assemble Model A.pdf
2024-07-14 Add files via upload
    In the following PDF, you will find detailed instructions on assembling the original model of our robot. The information is sourced from: https://bc-robotics.com/shop/2wd-metal-chassis-kit-high-speed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
    En el siguiente PDF, encontrarás instrucciones detalladas sobre cómo ensamblar el modelo original de nuestro robot. La información proviene de: https://bc-robotics.com/shop/2wd-metal-chassis-kit-high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
2024-07-15 Create 03. Sensor management.md
2024-07-15 Create 04. BOM
2024-07-15 Rename 04. BOM to 04. BOM.md
2024-07-15 Update 04. BOM.md
2024-07-16 Add files via upload
    In the following PDF, you will find detailed information about the connection diagrams. To view these diagrams in high quality, you can download the corresponding .fzpz files. || En el siguiente PDF 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
2024-07-17 Create 0.5 Mobility Management - Motors.md
2024-07-17 Rename 0.5 Mobility Management - Motors.md to 05. Mobility Management - Motors.md
2024-07-17 Update 05. Mobility Management - Motors.md
2024-07-18 Update README.md
    El archivo README.md se ha sustituido por un documento titulado "Introducción" con el objetivo de mejorar la claridad y la comprensión del repositorio en GitHub.
2024-07-22 Add files via upload
    Las bibliotecas proporcionadas son para la utilización del giroscopio y acelerómetro MPU6050: puede visitar el contenido de las librerías de los autores originales en los siguientes enlaces:
    https://github.com/ZHomeSlice/Simple_MPU6050
    https://github.com/jrowberg/i2cdevlib
2024-07-22 Add files via upload
    La biblioteca proporcionada es para la utilización del giroscopio y acelerómetro MPU6050: puede visitar el contenido de las librerías del autor original en el siguiente enlace:
    https://github.com/ZHomeSlice/Simple_Wire
2024-08-09 Update 03. Sensor management.md
